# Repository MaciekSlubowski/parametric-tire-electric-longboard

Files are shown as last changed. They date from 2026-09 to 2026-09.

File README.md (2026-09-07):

# 🛞 Parametric TPU Tire for Electric Longboards

<div align="center">
  parametric-tire-3d
  parametric-tire
</div>
<br>

A customizable, 3D-printable tire designed specifically for electric longboards, mountainboards, and DIY off-road vehicles using split rims. 

Written in OpenSCAD, this model features an aggressive **hybrid tread pattern** (longitudinal grooves + directional V-tread + shoulder lugs).

## 📏 Default Dimensions
Based on the default parameters in the OpenSCAD file, the generated tire has the following physical dimensions (before material shrinkage):

* **Outer Diameter:** ~144.4 mm
* **Inner Diameter (Rim Fit):** ~92.4 mm *(Designed to shrink to approx. 91.1 mm after cooling)*
* **Total Tire Width:** 50 mm
* **Inner Rim Bed Width:** 43 mm
* **Tire Profile Thickness:** 19 mm

## ✨ Features
* **Supportless Printing:** All tread grooves and lugs use 45-degree chamfers, meaning you can print this entirely without supports.
* **Fully Parametric:** Easily adjust rim diameter, tire width, thickness, and tread depth in the OpenSCAD file to fit your specific hubs.
* **All-Terrain Design:** Built for grip on both pavement and light off-road trails.

## 🖨️ Recommended Print Settings
To get the best ride quality and durability out of this tire, follow these guidelines:

* **Material:** TPU (85A to 95A hardness works best - e.g., Rosa3D or similar)
* **Layer Height:** 0.2 mm - 0.28 mm
* **Walls/Perimeters:** 4-6 (for structural strength)
* **Infill:** **100% Solid (MANDATORY)** - The tire must be printed completely solid. Sparse infill patterns will cause the tire to collapse or tear under the weight, torque, and lateral forces of an electric longboard.
  * *Pro-Tip for 100% TPU:* Use a criss-cross infill pattern (like *Rectilinear* or *Lines* with alternating angles, e.g., 45° and -45°). To maximize durability, the infill lines should not stack perfectly on top of each other vertically. Ensure your slicer slightly offsets (shifts) the paths laterally on subsequent layers. This creates a tightly interwoven internal structure that significantly increases strength while preventing material buildup, bulging, and nozzle clogs common with solid TPU.
* **Supports:** NONE 
* **Cooling:** 100% (Crucial for steep overhangs in the tread)

## ⚠️ Note on Material Shrinkage
Flexible materials like TPU tend to shrink slightly after printing and cooling down. Based on my tests, the TPU shrank by exactly **1.4%**. 

* The default `rim_radius` parameter in the OpenSCAD file (46.2 mm) is already slightly enlarged to compensate for this 1.4% shrinkage, ensuring a tight, secure fit on a standard split rim once cooled. 
* If your printed tire ends up too tight or too loose for your specific hubs (as different TPU brands may vary), you can either adjust the `rim_radius` variable directly in the code or scale the final STL model by 1-2% on the X and Y axes in your slicer.

This project is open-source and provided strictly for personal, educational, and non-commercial purposes. You are free to explore, modify, and learn from the codebase. If you wish to use this project for commercial purposes, please contact me.

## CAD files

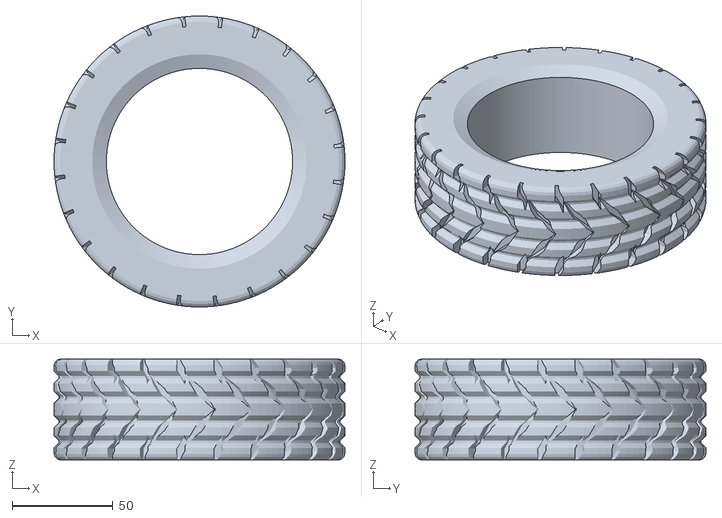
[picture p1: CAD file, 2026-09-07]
parametric-tire-electric-longboard.stl
144.4 x 144.4 x 50.0

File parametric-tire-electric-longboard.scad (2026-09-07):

/* =====================================================================
   PROJECT: TPU ALL-TERRAIN TIRE FOR SPLIT RIMS
   VERSION: HYBRID TREAD DESIGN
   
   DESCRIPTION:
   A parametric, 3D-printable TPU tire designed for electric longboards 
   or similar off-road vehicles using split rims. Features a hybrid 
   tread pattern with 4 longitudinal grooves, a directional V-tread, 
   and aggressive shoulder lugs. 
   
   FDM OPTIMIZED:
   All tread cuts utilize 45-degree angles to ensure clean, supportless 
   printing on standard FDM 3D printers.
   ===================================================================== */

// --- TIRE PARAMETERS (in millimeters) ---
rim_radius = 46.2;       // Slightly enlarged inner diameter (compensates for TPU shrinkage, yields ~91.1mm)
inner_width = 43;        // Width of the rim bed
inner_depth = 7;         // Depth of the rim bed fit
outer_width = 50;        // Total width of the tire
tire_thickness = 19;     // Thickness of the tire profile

// --- TREAD PARAMETERS ---
groove_count = 24;       // Number of transverse tread blocks
long_groove_depth = 2.5; // Depth of the continuous longitudinal grooves
tread_depth = 3.5;       // Depth of the V-tread and shoulder lugs

// --- RENDER SETTINGS ---
$fn = 120;               // High resolution for smooth curves
outer_radius = rim_radius + inner_depth + tire_thickness;

/* =====================================================================
   MODULES
   ===================================================================== */

/* 
 * fdm_cut: Generates a diamond-shaped cutting tool.
 * Uses 45-degree overhang angles so the tread grooves can be printed
 * cleanly without requiring support material.
 */
module fdm_cut(depth, w, l) {
    rotate([0, 90, 0])
    linear_extrude(height = depth * 2, center = true)
    polygon([
        [l / 2, 0],
        [0, w / 2],
        [-l / 2, 0],
        [0, -w / 2]
    ]);
}

/* 
 * tpu_tire: Main geometry of the tire.
 * Combines the rounded profile, longitudinal grooves, and the directional 
 * tread pattern using boolean difference.
 */
module tpu_tire() {
    difference() {
        
        // 1. MAIN TIRE BODY (Rounded edges + 4 Longitudinal Grooves)
        rotate_extrude() {
            polygon(points=[
                // --- INNER RIM FIT ---
                [rim_radius, inner_width / 2],
                [rim_radius, -inner_width / 2],
                [rim_radius + inner_depth, -inner_width / 2],
                [rim_radius + inner_depth, -outer_width / 2],
                
                // --- BOTTOM EDGE ROUNDING (Fillet) ---
                [outer_radius - 3, -outer_width / 2],
                [outer_radius - 1.5, -outer_width / 2 + 0.5],
                [outer_radius - 0.5, -outer_width / 2 + 1.5],
                [outer_radius, -outer_width / 2 + 3],        
                
                // --- 4 LONGITUDINAL GROOVES (45° chamfers for FDM) ---
                // Groove 1
                [outer_radius, -19],                
                [outer_radius - long_groove_depth, -16.5],
                [outer_radius - long_groove_depth, -15.5],
                [outer_radius, -13],                
                
                // Groove 2
                [outer_radius, -9],                
                [outer_radius - long_groove_depth, -6.5],  
                [outer_radius - long_groove_depth, -5.5],  
                [outer_radius, -3],                
                
                // Groove 3
                [outer_radius, 3],                  
                [outer_radius - long_groove_depth, 5.5],   
                [outer_radius - long_groove_depth, 6.5],   
                [outer_radius, 9],                  
                
                // Groove 4
                [outer_radius, 13],                
                [outer_radius - long_groove_depth, 15.5],  
                [outer_radius - long_groove_depth, 16.5],  
                [outer_radius, 19],    
                
                // --- TOP EDGE ROUNDING (Fillet) ---
                [outer_radius, outer_width / 2 - 3],
                [outer_radius - 0.5, outer_width / 2 - 1.5],
                [outer_radius - 1.5, outer_width / 2 - 0.5],
                [outer_radius - 3, outer_width / 2],
                
                [rim_radius + inner_depth, outer_width / 2]                        
            ]);
        }
        
        // 2. DIRECTIONAL TRANSVERSE TREAD PATTERN
        for(i = [0 : groove_count - 1]) {
            rotate([0, 0, i * (360 / groove_count)]) {
                
                // --- CENTER: Directional "V" pattern ---
                translate([outer_radius, 0, 9])
                    rotate([40, 0, 0])
                    fdm_cut(tread_depth + 1, 4, 25);
                    
                translate([outer_radius, 0, -9])
                    rotate([-40, 0, 0])
                    fdm_cut(tread_depth + 1, 4, 25);
                    
                // --- SIDES: Aggressive Off-Road Shoulder Lugs ---
                // Offset by half a step to interleave with the center V-pattern
                rotate([0, 0, 180 / groove_count]) {
                    
                    translate([outer_radius, 0, 20])
                        rotate([15, 0, 0])
                        fdm_cut(tread_depth + 1.5, 4.5, 16);
                        
                    translate([outer_radius, 0, -20])
                        rotate([-15, 0, 0])
                        fdm_cut(tread_depth + 1.5, 4.5, 16);
                }
            }
        }
    }
}

/* =====================================================================
   MODEL GENERATION
   ===================================================================== */
tpu_tire();
